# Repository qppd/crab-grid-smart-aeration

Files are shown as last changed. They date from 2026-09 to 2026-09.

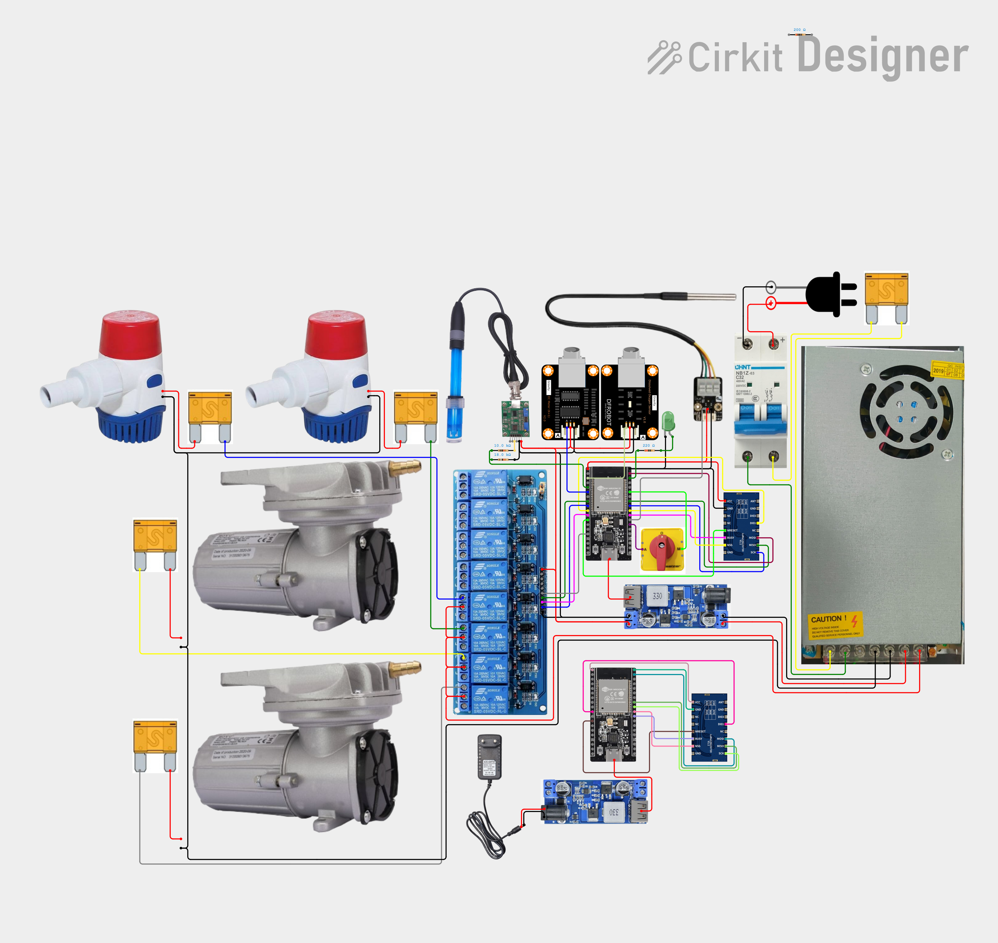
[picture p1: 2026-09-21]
wiring/circuit_image.png

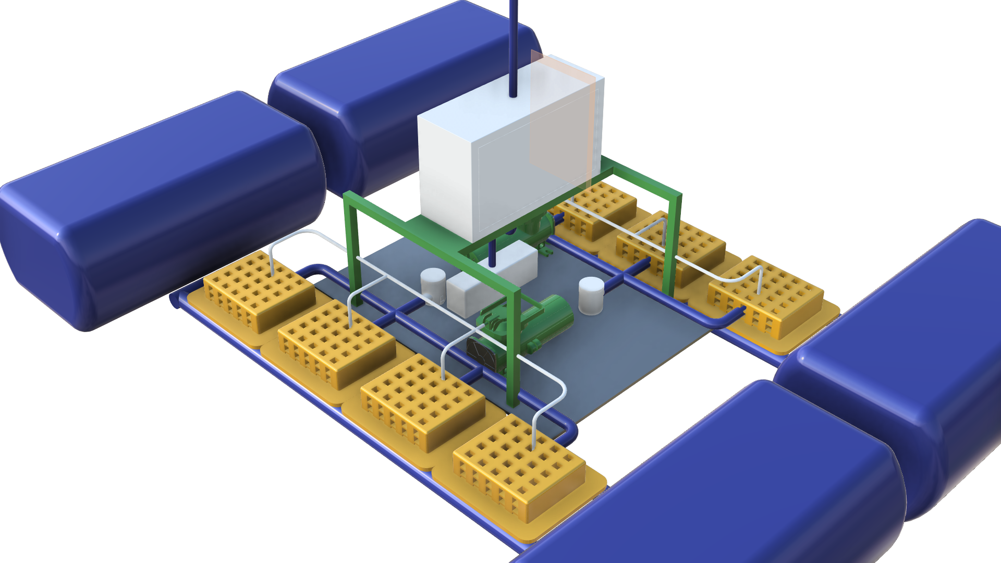
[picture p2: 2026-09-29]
model/SmartCrabAeration1.png

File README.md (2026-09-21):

<div align="center">

# Solar Automated LoRa-Integrated Mud Crab Aeration Network with Crab Grid Observation

A house-powered, remotely monitored smart aquaculture system for mud crab fattening in mangrove areas — combining physical crab separation, continuous water quality monitoring, automated aeration and alerts, LoRa remote control, and overhead visual security.





[]()

**Author:** [QPPD](https://www.github.com/qppd)

</div>

---

## Table of Contents

- [About the Project](#about-the-project)
- [Core Capabilities](#core-capabilities)
- [System Architecture](#system-architecture)
- [Structure & Layout](#structure--layout)
- [Electronics & Hardware](#electronics--hardware)
- [Power System](#power-system)
- [Software & Firmware](#software--firmware)
- [BOM & Budget](#bom--budget)
- [Getting Started](#getting-started)
  - [Prerequisites](#prerequisites)
  - [Hardware Setup](#hardware-setup)
  - [Firmware Installation](#firmware-installation)
  - [Dashboard Configuration](#dashboard-configuration)
- [Project Structure](#project-structure)
- [Compatibility Notes](#compatibility-notes)
- [Roadmap](#roadmap)
- [Contributing](#contributing)
- [License](#license)
- [Contact](#contact)

---

## About the Project

Mud crab (*Scylla serrata*) fattening is a vital livelihood in Southeast Asian mangrove communities, but crabs are notoriously cannibalistic — they eat each other when crowded or molting. Traditional farming relies on manual water monitoring, which is reactive rather than proactive. In these remote mangrove areas there is no utility grid and no Wi-Fi, and whatever power exists comes from small household solar systems — which makes conventional IoT solutions impractical.

This project solves these problems with a **low-power, remotely monitored aquaculture system** that:

1. Physically protects crabs using individual floating cages
2. Continuously senses water quality with multiple environmental sensors
3. Automatically triggers aeration and alerts; salinity correction is treated as a controlled test function, not a guaranteed open-water correction
4. Transmits data over **LoRa** to a bridge node at the house (where WiFi exists) for real-time remote monitoring
5. Provides visual security through an overhead camera system

The prototype is powered from the **household's existing solar installation** (220V AC, available 24/7 from the array, the inverter and a battery bank of over 600 Ah), so it needs no panels or batteries of its own — only a protected AC drop from the house to the float plus a 12V DC supply on site.

---

## Core Capabilities

| Feature | Description |
|---|---|
| **Physical Protection** | Individual floating cages (horizontal crab fattening boxes) physically separate crabs to prevent cannibalism. |
| **Water Quality Sensing** | Continuous monitoring of dissolved oxygen, pH, temperature and salinity — plus a pH/temperature-derived ammonia toxicity-risk indicator. Absolute NH₃ concentration requires a TAN measurement or laboratory test. |
| **Automated First Aid** | When conditions become dangerous, the system forces aeration, raises an alarm, and logs the event. Open-water salinity correction is not assumed; brine dosing is only valid in an isolated or closed-loop test enclosure. |
| **Manual & Automatic Control** | Runs itself in **AUTO** (firmware thresholds drive the pumps) and accepts **MANUAL** or **OFF** from the dashboard webapp, with a physical selector on the box as the fail-safe. |
| **Remote Monitoring & Control** | LoRa carries sensor data and pump commands to the house bridge node, which feeds the remote dashboard — even where there is no internet or Wi-Fi at the pond. |
| **Visual Security** | Overhead camera to monitor crab molting, deter animal predators, and spot human poachers. |

---

## System Architecture

```
                            ┌─────────────────────────────────────┐
                            │      REMOTE DASHBOARD (Next.js      │
                            │         + Firebase webapp)          │
                            └──────────────┬──────────────────────┘
                                           │ Internet / WiFi
                                           │
                            ┌──────────────┴──────────────────────┐
                            │  House Bridge Node (ESP32 + E22)    │
                            │  at the house, where WiFi exists    │
                            └──────────────┬──────────────────────┘
                                           │ LoRa (915 MHz, P2P)
                            ┌──────────────┴──────────────────────┐
                            │   ESP32 DevKit + E22 (SX1262)       │
                            │       — Main Controller Node        │
                            └──┬─────┬──────┬──────┬──────┬───────┘
                               │     │      │      │      │
                  ┌────────────┘     │      │      │      └────────────┐
                  │                  │      │      │                   │
          ┌───────┴────────┐  ┌─────┴────┐ │ ┌────┴───────┐  ┌───────┴──────┐
          │  Water Sensors │  │  Relay   │ │ │  Camera    │  │  House Solar │
          │  · EC/Salinity │  │  Module  │ │ │  ESP32-CAM-MB │  │  AC Feed     │
          │  · pH Probe    │  │  (8-Ch)  │ │ │  OV2640    │  │  · 220V 24/7 │
          │  · DS18B20 ×2  │  └────┬─────┘ │ └────────────┘  │  · RCD 30mA  │
          │  · DO Sensor   │       │       │                  │  · 12V 30A   │
          └────────────────┘  ┌────┴─────┐ │                  │    PSU       │
                              │ Actuators│ │                  └──────────────┘
                              │ · Air    │ │
                              │   Pumps  │ │
                              │ · Bilge  │ │
                              │   Pumps  │ │
                              └──────────┘ │
                                           │
                              ┌─────────────┴───────────┐
                              │   8 × Individual Crab   │
                              │   Fattening Boxes on     │
                              │   Foam Pontoon Grid      │
                              └─────────────────────────┘
```

---

## Structure & Layout

| Specification | Detail |
|---|---|
| **Pond Area** | 500 sqm (modular conceptual prototype) |
| **Capacity** | 8 individual fattening boxes on the pontoon grid, one crab per box (the anti-cannibalism constraint) |
| **Boxes & frames** | Slotted plastic boxes, shaded under the frame; frame/gantry preferably UV-stabilized PVC/FRP, or marine-grade timber sealed with marine epoxy/PU and Grade 316/nylon fasteners |
| **Floaters** | Ready-made foam-filled pontoon floats (×8–12), each with a manufacturer-rated buoyancy of at least 50 kg. Final sizing uses the measured dry above-water load and load distribution; water inside slotted cages is not counted as dead load while submerged. The PVC pipes are **conduit, never flotation**: water-filled pipe weighs ~1 kg per litre (see [Components.md](docs/Components.md)). |
| **Aeration** | 2 × RESUN MPQ-03 (MPQ-903) 12V air pumps (35W, 68 L/min open-flow, 6 outlets) + air stone per cage — regulate and measure the delivered flow. The biological target is approximately 4.8–6.4 L/min total for 320 L (1.5–2 L/min per 100 L), with N+1 redundancy. |
| **Air & water routing** | Two separate circuits inside the PVC pipe grid: an air header with per-cage drop tubes and stones, and a water header fed by the bilge pumps with a valved outlet per cage. Flexible hose runs from pump to cage are an option/backup |
| **Sensor hub** | Centred on the grid for balance and symmetric cable runs; probes at mid-depth (~20–30 cm), clear of the aerator plume. The DO probe must have gentle water movement across its membrane; one probe is a single-point risk, so use a handheld meter or scheduled aeration as a fallback. |
| **Controller & Power** | Controller centred in the setup for optimal wiring. Powered by a 220V AC drop from the household solar system (24/7) → shore-end 30 mA RCD + 2-pole breaker → weatherproof feedthroughs → 12V 30A DC supply. The AC installation and conductor/fuse sizing require a licensed electrician and Philippine Electrical Code review. |

> See [`Components.md`](docs/Components.md) for the full component specifications and [`docs/BOM.md`](docs/BOM.md) for the detailed Bill of Materials with verified product links and pricing.

---

## Electronics & Hardware

| Component | Specification | Purpose |
|---|---|---|
| **ESP32 DevKit 38-pin + EBYTE E22-900M22S (SX1262)** | ESP32-WROOM-32 + 915 MHz LoRa (SX1262, up to +22 dBm) | Main controller node — reads all sensors, runs automation logic, communicates over point-to-point LoRa on the 915 MHz ISM band. Verify measured EIRP and NTC type-approval before deployment. |
| **House Bridge Node (ESP32 + E22-900M22S)** | Same radio stack, at the house | LoRa ⇄ WiFi bridge — pushes float telemetry to the Firebase dashboard and relays dashboard commands back down over LoRa |
| **ESP32-CAM-MB** | OV2640, WiFi/BT | Overhead camera node for visual monitoring |
| **8-Channel Relay Module** | 12V coil, optocoupler, low-level trigger | Drives aerators and salinity pumps with spare channels |
| **DFRobot EC/Salinity Sensor** | K=10, 0–100 mS/cm | Measures conductivity/salinity. Use the manufacturer/PSS-78 conversion rather than a fixed 0.66 ppt-per-mS/cm rule; 35 ppt seawater is approximately 53 mS/cm at 25 °C. |
| **pH Electrode E-201-C** | PH-4502C analog board | Monitors pH (target: 7.5–8.5 for brackish water) |
| **DS18B20 Temperature Probes** | Waterproof, stainless steel ×2 | Digital temperature sensing (1-Wire) |
| **DFRobot Dissolved Oxygen Kit** | SEN0237-A, galvanic probe — **one unit (single measurement point)** | Measures dissolved oxygen — the #1 crab killer; mounted on the centred hub with water movement across the membrane. Carry a handheld DO meter and spare membrane/electrolyte because one probe is a single-point failure. |
| **12V DC Air Pumps (RESUN MPQ-03)** | Electromagnetic, 35W, 68 L/min open-flow, 0.068 MPa, ~3.5A, 6 outlets each ×2 | Oxygenation for all 8 cages; regulate each branch to the measured biological target (about 0.6–0.8 L/min per cage for 4.8–6.4 L/min total) + N+1 redundancy (alternating duty). Huge open-flow headroom covers depth/tubing/stone losses — must not be dumped unregulated into the cages. |
| **12V Marine Bilge Pumps** | 1100 GPH, submersible ×2 | Water circulation/flushing and a controlled salinity experiment. Do not claim reliable salinity correction in open slotted cages: tidal flushing and dense brine sinking will defeat dosing unless the cage is temporarily isolated or the test is closed-loop. |

---

## Power System

| Component | Specification |
|---|---|
| **AC Source** | 220V AC drop from the household solar system (array + **>600 Ah** battery bank + inverter) — available 24/7 |
| **AC Protection** | 30 mA RCD/GFCI + 2-pole breaker at the house end; outdoor-rated earthed cable (2.5 mm²) run overhead or in conduit; IP67/IP68 weatherproof connectors, drip loops, no submerged joints, monthly RCD test, and licensed-electrician commissioning. |
| **On-Site DC Supply** | 12V 30A (360 W) switching PSU → pumps, relay module, controller; LM2596S 24V/12V → 5V USB step-down module for the camera node. Treat 30A and the branch fuses as provisional until pump nameplate current, inrush, conductor ampacity, and voltage drop are measured and signed off. |

**Night load:** the planning estimate is ~50–60 W (≈ 5 A at 12 V) for aeration, but verify the actual pump duty cycle and inverter losses before relying on the household bank. The full Power Budget is in [`docs/BOM.md`](docs/BOM.md).

> **Single point of failure:** no on-site battery, so a tripped breaker or a cut cable stops aeration. The house bridge must alarm on heartbeat loss; use a local UPS/supercapacitor only if a last-gasp packet or unattended-night runtime is required.

---

## Software & Firmware

- **Microcontroller Firmware:** ESP32 (Arduino/PlatformIO) — sensor reading, LoRa P2P communication, relay control
- **LoRa Link:** point-to-point 915 MHz (E22-900M22S / SX1262) between the float node and the house bridge node — no LoRaWAN server (TTN/ChirpStack) needed. 915 MHz is the Philippine NTC licence-free SRD band for this low-duty telemetry; confirm maximum EIRP and type-approval before deployment.
- **Dashboard:** a **Next.js + Firebase (Realtime Database + Auth)** webapp — the house bridge node writes sensor data into the Realtime Database, and dashboard commands are read back and relayed down over LoRa
- **Camera:** WiFi-based streaming from ESP32-CAM-MB (local AP during pond visits)

### Control Modes

| Mode | Drives the pumps | When to use |
|---|---|---|
| **AUTO** (default) | Firmware thresholds — low salinity → bilge pump, low DO → aerator | Normal operation, and the fallback whenever anything else fails |
| **MANUAL** | The operator, per pump, from the webapp or the local selector | Testing, calibration, maintenance, harvest |
| **OFF** | Nobody — all actuators off | Servicing the float only; never while crabs are stocked |

Rules the firmware enforces:

- Boot, reset or link loss → **AUTO**, with aeration defaulting **ON**
- MANUAL auto-reverts to AUTO after 5 min without a command, so a forgotten switch cannot disable life-support aeration
- A DO reading below 3 ppm overrides MANUAL, forces aeration on, sends an immediate emergency uplink and raises an alarm
- The float sends a heartbeat at least every 60 seconds; the house bridge alarms on missed heartbeats
- Mode and pump state are echoed in every uplink, so the dashboard shows what the device actually believes

**Downlink packet:** device ID + sequence number + mode/pump command + expiry/ack field + CRC-8. The receiver validates the ID and CRC, applies the command only if it is fresh, and returns an ACK/NAK. Normal polling may be 5–15 minutes, but emergency sensor events bypass the schedule.

---

## BOM & Budget

Every part, price, product link and rating lives in [`docs/BOM.md`](docs/BOM.md), together with the compatibility verification and the power budget. Headline totals: **Tier 1 sensors ≈ ₱39,787–48,879**; **full sensor set ≈ ₱53,182–63,473** (per-category ranges are in the BOM).

Purchase is phased to match the project timeline — the four phases add up to the build total above (≈ **₱53,182–63,473** at item prices):

### Phase 1 — Bench Testing (~₱2,906)
2 × ESP32 DevKit + 2 × E22-900M22S/915 MHz antenna + DS18B20 + relay module + one bilge pump + the AUTO/OFF/MANUAL selector → build & test the control loop and the LoRa link on the bench (12V from a lab supply, or buy the on-site PSU now).

### Phase 2 — Remote Dashboard (~₱7,127–7,727)
House bridge node (ESP32 + E22-900M22S) + EC/salinity sensor + refractometer + calibration standard → close the remote monitoring loop.

### Phase 3 — Power to the Float (~₱3,127–4,969)
Protected 220V AC drop from the house (30 mA RCD + breaker) + 12V 30A DC supply + LM2596S camera module + fuses/glands → run the float off the household solar system. A licensed electrician must install and commission the mains side.

### Phase 4 — Full Feature Set (~₱34,850–46,400)
DO sensor + pH sensor (+ buffers) + ESP32-CAM-MB camera + second circulation pump + fattening boxes + frame/netting + **4× round foam floats 50×90** + the PVC air/water grid + sensor hub + air pumps + misc hardware + a controlled salinity-test setup → complete system before deployment. Open-water brine correction is not a guaranteed feature.

---

## Getting Started

### Prerequisites

- [Arduino IDE](https://www.arduino.cc/en/software) or [PlatformIO](https://platformio.org/)
- ESP32 board package (esp32 by Espressif)
- `RadioLib` (LoRa/SX1262 driver for the E22-900M22S) · `OneWire` / `DallasTemperature` (DS18B20) · `DFRobot_EC` / `DFRobot_pH` (DFRobot sensors)
- 3 × ESP32 DevKit 38-pin + 3 × E22-900M22S + 915 MHz antennas (float node, house bridge, spare — see [`docs/BOM.md`](docs/BOM.md) §1)
- pH/EC calibration standards and a handheld refractometer (see [`docs/BOM.md`](docs/BOM.md) §6)

### Hardware Setup

1. **Scaffold the floating grid** on foam-filled pontoon floats, with the frame and gantry in UV-stabilized PVC/FRP or properly sealed marine-grade material; use Grade 316 stainless or nylon fasteners in brackish water.
2. **Mount the 8 fattening boxes** on the grid, one crab per box, shaded from direct sun.
3. **Position the controller node** (ESP32 + E22-900M22S) in the centre of the setup in an IP65 enclosure.
4. **Connect the sensors** to the ESP32 ADC/GPIO pins per the pin map in [`Components.md`](docs/Components.md). For the minimum pH divider use 10 kΩ series + 18 kΩ shunt (5 V → about 3.21 V); for professional-grade pH, use an ADS1115 I2C ADC and 3.3 V level shifting.
5. **Wire the relay module** to the air pumps and bilge pumps, following the WiFi/boot-safe pin map in [`Components.md`](docs/Components.md) (no analog on ADC2 pins while WiFi runs, nothing on boot-strap pins 0/12/15).
6. **Run the power drop** — 220V AC from the house (30 mA RCD + breaker at the house end, weatherproof IP67/IP68 terminations, drip loops, no submerged joints) → 12V 30A DC supply on the float → fused distribution. Have a licensed electrician verify conductor size, earthing, breaker coordination and Philippine Electrical Code compliance.
7. **Calibrate before trusting any reading** — 2-point pH (4.01 / 6.86), EC with 1.413 mS/cm and 12.88 mS/cm standards following the sensor procedure, and cross-check salinity with the refractometer. Treat 12.88 mS/cm as a conductivity standard, not as 35 ppt seawater.

### Firmware Installation

1. Create the `firmware/` directory (planned — see [Project Structure](#project-structure)) and open it in Arduino IDE or PlatformIO.
2. Install required libraries:
   - `RadioLib` (SX1262 — the E22-900M22S needs RadioLib's SX126x driver; SPI SCK 18/MISO 19/MOSI 23/NSS 5, RST 14, DIO1 26, BUSY 17)
   - `OneWire` / `DallasTemperature` (DS18B20)
   - `DFRobot_EC` / `DFRobot_pH` (DFRobot sensors)
3. Configure the radio settings identically on every node (915 MHz, SF9–12, matching bandwidth/coding rate/sync word). Record the configured output/EIRP and confirm NTC type-approval for the 915 MHz SRD band.
4. WiFi stays **off** on the float node; only the house bridge joins the network.
5. Upload the firmware to each ESP32. Implement the device-ID/sequence/CRC-8 packet, ACK/NAK, 60-second heartbeat, immediate DO emergency uplink, and 5-minute MANUAL auto-revert before any life-support test.

### Dashboard Configuration

1. **Create the back end** — a Firebase project with the **Realtime Database** (live telemetry) and Firebase Auth for the farmer accounts.
2. **Deploy the webapp** — a Next.js app on Vercel's free tier (or Firebase Hosting), with the service-account values set as env vars: `FIREBASE_DATABASE_URL`, `FIREBASE_PROJECT_ID`, `FIREBASE_CLIENT_EMAIL`, `FIREBASE_PRIVATE_KEY`.
3. **Connect the uplinks** — the house bridge node relays each float packet into the Realtime Database (`devices/<id>/state`), where the webapp's `onValue()` listeners stream it straight to the UI.
4. **Build the control panel** — live readings, pump state, the AUTO/MANUAL/OFF selector, per-pump overrides and alert thresholds; a route handler writes the command into the Realtime Database where the house bridge polls it and relays it down over LoRa.

---

## Project Structure

```
crab-grid-smart-aeration/
├── README.md              # This file — start here
├── LICENSE                # MIT License
├── .gitignore
├── docs/                   # Documentation and builder guides
│   ├── Components.md      # Engineering specs and validation rationale
│   ├── HARDWARE.md        # Hardware guide (specs, pin map, BOM mirror)
│   ├── BOM.md             # Bill of Materials — prices, product links, ratings
│   ├── SETUP.md           # Environment, accounts and first power-up
│   ├── WIRING.md          # Assembly, wiring and verified ESP32 pin map
│   ├── FIRMWARE.md        # Firmware architecture and packet protocol
│   ├── TESTING.md         # Test plan and acceptance criteria
│   ├── CALIBRATION.md     # Sensor calibration procedures
│   ├── TROUBLESHOOTING.md # Fault isolation guide
│   ├── APP.md             # Dashboard webapp specification
│   ├── SYSTEM-ARCHITECTURE.md # Thesis system architecture diagram (Mermaid)
│   ├── BLOCK-DIAGRAM.md   # Thesis hardware block diagram (Mermaid)
│   ├── FLOWCHART.md       # Thesis operational flowchart (Mermaid)
│   ├── STACKS.md          # Technology stack reference
│   └── images/            # planned
├── firmware/              # planned — ESP32 source code
│   ├── main_controller/  # planned — ESP32+E22-900M22S sensor + LoRa firmware
│   ├── house_bridge/     # planned — LoRa ⇄ WiFi relay node firmware
│   └── camera_node/      # planned — ESP32-CAM-MB streaming firmware
└── dashboard/            # planned — Next.js + Realtime Database webapp

Items marked "planned" are not yet in the repository — create each item as its roadmap phase completes.
```

---

## Compatibility Notes

All system-level checks, with their verdicts, are in [`docs/BOM.md`](docs/BOM.md). The following gates still need action before deployment:

| Open item | Action |
|---|---|
| Camera is WiFi-only (video cannot fit LoRa) | Use its own AP during pond visits, run it at the house with the bridge node, or fit an LTE camera |
| No affordable NH₃ sensor | pH + temperature can estimate the toxic fraction/risk only; absolute NH₃ requires measured TAN or a laboratory test |
| PH-4502C outputs up to 5V | Use 10 kΩ series + 18 kΩ shunt for the minimum divider, or an ADS1115 for better precision |
| No on-site battery | Alert on heartbeat loss at the house bridge; confirm the house inverter stays on 24/7; add a small 12V UPS or supercapacitor if a last-gasp packet or unattended-night runtime is required |
| Control needs internet, hosting and the bridge node | Local selector as fail-safe; MANUAL auto-reverts to AUTO after 5 minutes; emergency sensor events bypass the polling interval; ACK/NAK confirms commands |

---

## Roadmap

- [x] Concept definition and documentation
- [x] Component selection and BOM verification
- [ ] Phase 1: Bench testing with ESP32 + E22-900M22S + basic sensors
- [ ] Phase 2: House bridge node integration and remote dashboard
- [ ] Phase 3: Power to the float (AC drop from household solar + 12V DC supply)
- [ ] Phase 4: Full feature set (DO, pH, camera, boxes)
- [ ] NTC/Philippine Electrical Code sign-off and licensed-electrician commissioning
- [ ] Field testing in mangrove environment
- [ ] System validation

---

## Contributing

Contributions are welcome! Please feel free to submit a Pull Request or open an Issue.

1. Fork the repository
2. Create your feature branch (`git checkout -b feature/amazing-feature`)
3. Commit your changes (`git commit -m 'Add some amazing feature'`)
4. Push to the branch (`git push origin feature/amazing-feature`)
5. Open a Pull Request

---

## License

Distributed under the MIT License. See [`LICENSE`](LICENSE) for more information.

---

## Contact

**QPPD** — [github.com/qppd](https://www.github.com/qppd)

Project Link: [https://github.com/qppd/crab-grid-smart-aeration](https://github.com/qppd/crab-grid-smart-aeration)

---

<div align="center">

**Built with love for sustainable aquaculture**

</div>

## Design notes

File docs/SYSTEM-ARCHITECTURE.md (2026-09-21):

# System Architecture

**Project:** Solar Automated LoRa-Integrated Mud Crab Aeration Network with Crab Grid Observation

This document describes the system architecture in the format required . The system is organized into five layers, from pond-side sensing to the cloud-hosted dashboard, connected by a 915 MHz LoRa point-to-point link where no WiFi exists.

## 1. Architecture Diagram

```mermaid
flowchart TB
    subgraph L1["Layer 1 - Sensing Layer (pond)"]
        S1["EC/salinity probe, K=10, 0-100 mS/cm"]
        S2["pH electrode E-201-C with PH-4502C board"]
        S3["DS18B20 temperature probes, 2 units"]
        S4["Dissolved oxygen probe, SEN0237-A"]
        S5["ESP32-CAM-MB OV2640 overhead camera"]
    end

    subgraph L2["Layer 2 - Edge Control Layer (float node)"]
        C1["ESP32 DevKit + EBYTE E22-900M22S, main controller"]
        C2["8-channel relay module, 12 V coil, low-level trigger"]
        C3["RESUN MPQ-03 air pumps, 2 units, N+1 alternating duty"]
        C4["12 V bilge pumps, 2 units, circulation and flushing"]
        C5["Local AUTO / OFF / MANUAL selector and status LEDs"]
    end

    subgraph L3["Layer 3 - Communication Layer"]
        R1["LoRa point-to-point link, 915 MHz, SX1262"]
    end

    subgraph L4["Layer 4 - Gateway Layer (house)"]
        G1["House bridge node, ESP32 + E22-900M22S"]
    end

    subgraph L5["Layer 5 - Application Layer"]
        F1["Firebase Realtime Database, live telemetry and command queue"]
        F2["Firebase Auth, farmer accounts"]
        D1["Next.js dashboard on Vercel free tier"]
    end

    S1 --> C1
    S2 --> C1
    S3 --> C1
    S4 --> C1
    S5 -. WiFi local AP during pond visits .-> D1
    C5 --> C1
    C1 --> C2
    C2 --> C3
    C2 --> C4
    C1 --> R1
    R1 --> G1
    G1 --> F1
    F1 --> D1
    D1 --> F1
    F1 --> G1
    G1 --> R1
    R1 --> C1
```

**Figure 1.** Five-layer system architecture of the automated aeration network.

## 2. Layer Descriptions

| Layer | Contents | Responsibility |
|---|---|---|
| 1 — Sensing | EC/salinity, pH, DO, 2 × DS18B20, overhead camera | Continuous water-quality measurement at mid-depth on a centred, removable hub |
| 2 — Edge control | ESP32 + E22, 8-channel relay, air pumps (N+1), bilge pumps, local selector | Runs the automation logic and first-aid rules autonomously; WiFi stays off |
| 3 — Communication | 915 MHz LoRa point-to-point (SX1262) | Uplinks telemetry and heartbeats; downlinks commands; no LoRaWAN server |
| 4 — Gateway | House bridge node (ESP32 + E22) where WiFi exists | Relays LoRa ↔ Firebase both directions; alarms on heartbeat loss |
| 5 — Application | Firebase Realtime Database + Auth; Next.js dashboard on Vercel | Live monitoring, control, parameter management, alerts, history ([`APP.md`](APP.md)) |

## 3. Data Flow

| Direction | Path | Contents |
|---|---|---|
| Uplink (≤ 60 s heartbeat) | Sensors → float node → LoRa → bridge → RTDB → dashboard | Scaled DO, pH, EC, temperatures, mode, pump bitmap, flags |
| Emergency uplink (immediate) | Same path | DO below 3 ppm bypasses the schedule with the emergency flag |
| Downlink (next uplink cycle) | Dashboard → RTDB → bridge → LoRa → float node | Mode command, pump overrides, threshold/config updates; ID + seq + expiry + CRC-8 validated |
| Local (no cloud) | Selector → float node | AUTO/MANUAL/OFF fail-safe control independent of any network |

## 4. Design Rationale

1. **Autonomy first.** The pond has no grid, no WiFi, and no operator on site; the float node must keep crabs alive alone — hence fail-safe AUTO, 5-minute MANUAL revert, and aeration ON at boot.
2. **Point-to-point over LoRaWAN.** A single pond-to-house link needs no gateway subscription; the house bridge is the only WiFi-capable radio node.
3. **Separation of concerns.** Sensing, control, communication, gateway, and application layers can each be tested and replaced independently (see [`TESTING.md`](TESTING.md) gates).
4. **Single points of failure are watched.** The DO probe (one unit) has a documented handheld-meter fallback; the AC drop (no on-site battery) is watched by the bridge's heartbeat-loss alarm.
5. **Compliance gates.** 915 MHz operation respects the Philippine NTC licence-free SRD band; the 220 V AC drop is a licensed-electrician installation under the Philippine Electrical Code.

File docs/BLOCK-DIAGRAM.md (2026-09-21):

# Hardware Block Diagram

**Project:** Solar Automated LoRa-Integrated Mud Crab Aeration Network with Crab Grid Observation

This document presents the hardware block diagram in the format required . It shows the float node's power chain, controller, sensor cluster, LoRa radio, relay-driven actuators, and local interface, plus the radio link to the house bridge. Pin numbers follow the verified map in [`WIRING.md`](WIRING.md) §3.

## 1. Block Diagram

```mermaid
flowchart LR
    subgraph PWR["Power System"]
        AC["220 V AC from household solar, 24/7"] --> RCD["30 mA RCD + 2-pole breaker, shore end"]
        RCD --> PSU["12 V 30 A switching PSU, 360 W"]
        PSU --> BUCK["LM2596S 24 V/12 V to 5 V USB step-down"]
    end

    subgraph CTRL["Main Controller"]
        CORE["ESP32 DevKit 38-pin, ESP32-WROOM-32"]
    end

    subgraph SEN["Sensor Cluster"]
        S1["pH analog output to GPIO 34, ADC1"]
        S2["EC/salinity analog output to GPIO 35, ADC1"]
        S3["DO analog output to GPIO 36, ADC1"]
        S4["2x DS18B20 shared 1-Wire bus on GPIO 16"]
    end

    subgraph RAD["LoRa Radio"]
        R1["EBYTE E22-900M22S, SX1262: SPI 18/19/23/5, RST 14, DIO1 26, BUSY 17"]
    end

    subgraph RLY["Relay Module, 8-channel, GPIO 25 / 27 / 33 / 13"]
        K1["Channel 1"]
        K2["Channel 2"]
        K3["Channel 3"]
        K4["Channel 4"]
    end

    subgraph ACT["Actuators"]
        P1["RESUN MPQ-03 air pump 1, 35 W"]
        P2["RESUN MPQ-03 air pump 2, 35 W"]
        P3["12 V bilge pump 1, 1100 GPH"]
        P4["12 V bilge pump 2, 1100 GPH"]
    end

    subgraph LOC["Local Interface"]
        H1["3-position rotary selector on GPIO 4 and 21"]
        H2["Mode and status LEDs on GPIO 22 and 2"]
    end

    BR["House bridge node, ESP32 + E22-900M22S"]
    V1["ESP32-CAM-MB OV2640, 5 V from LM2596S module, WiFi AP only"]

    PSU --> CORE
    PSU --> K1
    BUCK --> V1
    S1 --> CORE
    S2 --> CORE
    S3 --> CORE
    S4 --> CORE
    CORE --> R1
    R1 --> CORE
    R1 -. 915 MHz LoRa point-to-point, uplink and downlink .-> BR
    CORE --> K1
    CORE --> K2
    CORE --> K3
    CORE --> K4
    K1 --> P1
    K2 --> P2
    K3 --> P3
    K4 --> P4
    H1 --> CORE
    CORE --> H2
```

**Figure 1.** Hardware block diagram of the float node and its link to the house bridge.

## 2. Block Descriptions

| Block | Function | Key interfaces |
|---|---|---|
| Power system | 220 V AC from the household solar installation, protected by a shore-end 30 mA RCD, converted to 12 V DC and 5 V DC | Licensed-electrician AC side; 12 V feeds pumps, relays and controller; 5 V feeds the camera |
| Main controller | ESP32-WROOM-32 runs the automation logic, LoRa protocol, and fail-safe rules | Three ADC1 analog inputs, 1-Wire, VSPI to the radio, four relay outputs |
| Sensor cluster | DO, pH, EC/salinity, and two temperature probes | Analog on GPIO 34/35/36 (ADC1); DS18B20 pair on GPIO 16 with a 4.7 kΩ pull-up |
| LoRa radio | EBYTE E22-900M22S (SX1262) at 915 MHz | SPI 18/19/23, NSS 5, RST 14, DIO1 26, BUSY 17; 3.3 V logic only |
| Relay module | 8-channel, 12 V coil, optocoupler, low-level trigger; four channels used, four spare | External 10 kΩ pull-ups hold relays OFF through boot and reset |
| Actuators | Two RESUN MPQ-03 air pumps (N+1 alternating duty) and two bilge pumps | Branch-fused 12 V feeds; per-cage valves on the water header |
| Local interface | 3-position AUTO/OFF/MANUAL selector and status LEDs | Active-LOW decode on GPIO 4/21; LEDs on GPIO 22/2 |
| Camera node | ESP32-CAM-MB OV2640 for overhead visual monitoring | WiFi AP during pond visits; never streams over LoRa |
| House bridge | Second ESP32 + E22 at the house | Relays LoRa ↔ Firebase in both directions |

## 3. Design Notes

1. All analog sensors sit on **ADC1** so the pin map stays valid even if WiFi is later enabled on a node ([`WIRING.md`](WIRING.md) §4).
2. No actuator is connected to a boot-strapping pin; GPIO 0, 12, 15 and UART0 pins 1/3 remain unconnected.
3. The relay module's low-level trigger is boot-safe: firmware drives the GPIOs HIGH before initialization and external pull-ups keep the inputs released during reset.
4. The pipe grid carries the air and water headers as separate circuits; it is conduit, never flotation ([`Components.md`](Components.md) — Floaters).

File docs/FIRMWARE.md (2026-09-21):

# Firmware Guide

**Project:** Solar Automated LoRa-Integrated Mud Crab Aeration Network with Crab Grid Observation

Design reference for the three ESP32 firmware targets. The controlling principles: **fail-safe to AUTO with aeration ON**, **WiFi stays off on the float**, and the system must keep crabs alive with zero internet, zero cloud, and zero operator.

## 1. Targets and Layout

```
firmware/
├── main_controller/    # Float node: sensors, control loop, LoRa
├── house_bridge/       # Bridge node: LoRa <-> Firebase relay + alarms
├── camera_node/        # ESP32-CAM-MB: WiFi AP stream only
└── shared/
    ├── pins.h          # Pin map (verified in WIRING.md §3)
    ├── packets.h       # Frame layouts and CRC-8
    └── config.h        # Device ID, radio, thresholds, timing
```

Libraries: `RadioLib` (SX1262), `OneWire` + `DallasTemperature`, `DFRobot_EC`, `DFRobot_pH`; the bridge adds the Mobizt `Firebase Arduino Client` library for Realtime Database writes.

## 2. Control Rules (enforced in firmware)

| Rule | Behavior |
|---|---|
| Boot, reset, or link loss | Mode = **AUTO**, aeration **ON** |
| MANUAL timeout | Auto-reverts to AUTO after **5 minutes** without a fresh command (`MANUAL_REVERT_MS`, configurable 1–30 min) |
| DO emergency | DO below 3 ppm overrides any mode, forces aeration ON, raises the local alarm, and sends an **immediate emergency uplink** |
| Heartbeat | One uplink at least every **60 s**; mode and pump state echoed in every frame |
| Command validation | Device ID + sequence + expiry + CRC-8 all checked; stale or corrupt frames are NAKed |
| OFF | All actuators off; exists for servicing only |
| Boot-safe outputs | Relay GPIOs driven HIGH (relays off) **before** pin init; external pull-ups hold relays off through reset ([`WIRING.md`](WIRING.md) §4) |

## 3. Pin Map (summary)

The full conflict verification is in [`WIRING.md`](WIRING.md) §3–4. Quick map: LoRa SPI 18/19/23, NSS 5, RST 14, DIO1 26, BUSY 17; 1-Wire 16; pH 34, EC 35, DO 36 (all ADC1); relays 25/27/33/13; selector 4 (A) and 21 (B); mode LED 22, link LED 2; spare 32 and 39; leave 0/12/15 and 1/3 unconnected.

## 4. Radio Configuration (identical on every node)

| Setting | Value |
|---|---|
| Frequency | 915.0 MHz (PH NTC licence-free SRD band — confirm measured EIRP and type-approval) |
| Spreading factor | SF9 (SF7–12 supported) |
| Bandwidth / coding rate | 125 kHz / 4-5 |
| Preamble | 8 |
| Sync word | 0x3444 (private; never LoRaWAN public) |
| CRC | On |
| TX power | Within the NTC EIRP limit |

## 5. Packet Protocol

All frames end in **CRC-8 (poly 0x07)** computed over the preceding bytes. Multi-byte values are little-endian, scaled ×100.

### 5.1 Uplink — float to bridge (17 bytes)

| Byte | Field | Notes |
|---|---|---|
| 0 | Device ID | 1 = float |
| 1–2 | Sequence number | uint16, increments per frame |
| 3 | Flags | Bits 0–1 mode (0 AUTO, 1 MANUAL, 2 OFF); bit 2 emergency (DO event); bit 3 sensor fault |
| 4 | Pump bitmap | Bit 0 air1, bit 1 air2, bit 2 bilge1, bit 3 bilge2 |
| 5–6 | DO (ppm ×100) | uint16 |
| 7–8 | pH (×100) | uint16 |
| 9–10 | EC (mS/cm ×100) | uint16 |
| 11–12 | Temperature 1 (°C ×100) | int16 |
| 13–14 | Temperature 2 (°C ×100) | int16 |
| 15 | Status/reserved | Uplink interval, uptime bucket |
| 16 | CRC-8 | Over bytes 0–15 |

### 5.2 Downlink — bridge to float (8 bytes)

| Byte | Field | Notes |
|---|---|---|
| 0 | Device ID | Must match |
| 1–2 | Command sequence | Echoed in the ACK |
| 3 | Mode command | 0 AUTO, 1 MANUAL, 2 OFF, 255 = no change |
| 4 | Pump override bitmap | 0xFF = no change; bits as uplink |
| 5–6 | Expiry (s) | Command invalid after this window |
| 7 | CRC-8 | Over bytes 0–6 |

### 5.3 ACK/NAK — float to bridge (4 bytes)

Byte 0 device ID; byte 1 `0x06` ACK or `0x15` NAK; byte 2 echoed command sequence (low byte); byte 3 CRC-8.

## 6. Timing

| Timer | Value | Purpose |
|---|---|---|
| Heartbeat/uplink | 60 s (`HEARTBEAT_MS`) | Telemetry + command check each cycle; a future low-power build may stretch this to 5–15 min |
| Emergency uplink | Immediate | DO below 3 ppm bypasses the schedule |
| MANUAL revert | 5 min | No fresh command → AUTO |
| Command expiry | Set per command | Reject stale downlinks |
| Sensor sampling | 1 s sample / 15 s average | Smooth ADC noise before uplink |
| Heartbeat-loss alarm (bridge) | No uplink for 90 s | Local alarm + RTDB alert |

## 7. Sensor Pipeline

1. Read DS18B20 pair over 1-Wire; pH/EC/DO through the DFRobot libraries with the calibration constants from [`CALIBRATION.md`](CALIBRATION.md).
2. Apply the pH divider correction (or use ADS1115 values directly) and temperature compensation per library docs.
3. Flag a **sensor fault** when a reading is physically impossible (e.g., pH outside 0–14, DS18B20 returns −127) — the fault bit rides the next uplink.
4. Persist calibration constants in NVS/EEPROM so a reboot never loses calibration.

## 8. House Bridge Node

- Receives uplinks, verifies ID + CRC-8, writes to `devices/<id>/state` and trims `logs/<id>/<timestamp>` (schema in [`APP.md`](APP.md) §2).
- Polls `commands/<id>/queue` every uplink cycle, relays fresh commands downlink, and marks each command `acked` / `naked` / `expired`.
- Raises the **heartbeat-loss alarm** after 90 s of silence (local LED/buzzer plus an RTDB alert) — this is the single-point-of-failure watchdog for the life-support load.
- WiFi joins the home network; the float node's WiFi is never enabled.

## 9. config.h Defaults

| Key | Default | Allowed range |
|-----|---|---|
| `DEVICE_ID` | 1 (float), 2 (bridge) | 1–254 |
| `RF_FREQ_MHZ` | 915.0 | fixed by NTC band |
| `RF_SF` / `RF_BW_KHZ` / `RF_CR` | 9 / 125 / 5 | identical on all nodes |
| `HEARTBEAT_MS` | 60000 | 30000–300000 |
| `MANUAL_REVERT_MS` | 300000 | 60000–1800000 |
| `DO_EMERGENCY_PPM` | 3.0 | 2.0–4.0 |
| `DO_TARGET_PPM` | 5.0 | 4.0–7.0 |
| `SAL_MIN_PPT` / `SAL_MAX_PPT` | 28 / 32 | 10–34 (min < max) |
| `PH_MIN` / `PH_MAX` | 7.5 / 8.5 | 6.5–9.0 (min < max) |
| `TEMP_MIN_C` / `TEMP_MAX_C` | 27 / 30 | 20–35 (min < max) |

Dashboard-side edits to thresholds arrive as config downlinks and are clamped to these ranges ([`APP.md`](APP.md) §6).

## 10. Camera Node (ESP32-CAM-MB)

- Uses the stock AI-Thinker OV2640 pinout; **no LoRa** — video cannot fit the LoRa link.
- Runs a WiFi **access point** (`crabcam-<id>`) joined by the farmer's phone during pond visits.
- Power: 5 V at ≥ 2 A from the LM2596S module; brownouts are the usual camera fault (see [`TROUBLESHOOTING.md`](TROUBLESHOOTING.md) §6).

## 11. Building and Flashing

1. Board: **ESP32 Dev Module**; flash 4 MB; upload 115200–921600; CPU 240 MHz.
2. Select the right COM port; hold **BOOT** if "Connecting..." never completes.
3. Flash the float node **before** wiring pumps, and confirm serial logs show sensor init and the first uplink.
4. Flash the bridge, then the camera last.
5. Version-tag every field deployment in git so a known-good firmware can be re-flashed at the pond.

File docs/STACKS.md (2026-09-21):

# Technology Stack

**Project:** Solar Automated LoRa-Integrated Mud Crab Aeration Network with Crab Grid Observation

A layer-by-layer reference of every technology the system uses, from the pond hardware to the hosted dashboard. Selection rationale and validation notes live in [`Components.md`](Components.md); the architecture view is in [`SYSTEM-ARCHITECTURE.md`](SYSTEM-ARCHITECTURE.md).

## 1. Stack at a Glance

```mermaid
flowchart TB
    N1["Next.js dashboard on Vercel"] --> F1["Firebase Realtime Database + Auth"]
    F1 --> B1["House bridge node, ESP32 + E22, WiFi"]
    B1 -. "915 MHz LoRa point-to-point" .-> N2["Float node, ESP32 + E22"]
    N2 --> H1["Sensors, relay module, air and bilge pumps on 12 V"]
```

**Figure 1.** Technology stack, from the hosted dashboard down to the pond hardware.

## 2. Hardware Stack

| Layer | Component | Qty | Role |
|---|---|-----|---|
| Edge controller | ESP32 DevKit 38-pin (ESP32-WROOM-32) | 3 (float, bridge, spare/dev) | Runs control logic and the LoRa link |
| Radio | EBYTE E22-900M22S (SX1262, 915 MHz) | 3 | Long-range point-to-point telemetry |
| Observation | ESP32-CAM-MB (OV2640) | 1 | Overhead visual monitoring over a WiFi AP |
| Sensing | DFRobot EC K=10, pH E-201-C + PH-4502C, DS18B20 ×2, DO SEN0237-A | 1 ea (temp ×2) | Water-quality measurement |
| Actuation | 8-channel relay, 2 × RESUN MPQ-03 air pumps, 2 × bilge pumps 1100 GPH | 1 set | Aeration and circulation |
| Power | 220 V AC drop + 30 mA RCD, 12 V 30 A PSU, LM2596S 5 V module | 1 set | Household-solar-fed power chain |
| Structure | 8 slotted fattening boxes, foam pontoons, PVC air/water grid, sensor hub | 1 set | Floating cage grid on the pond |

## 3. Firmware Stack

| Technology | Used by | Purpose |
|---|---|---|
| Arduino framework on ESP32 (Arduino IDE or PlatformIO) | all nodes | Build system and runtime |
| `RadioLib` | float, bridge | SX1262 driver for the E22-900M22S |
| `OneWire` + `DallasTemperature` | float | DS18B20 probes |
| `DFRobot_EC` / `DFRobot_pH` | float | EC and pH conversion with calibration |
| `Firebase Arduino Client Library` (Mobizt) | bridge | Realtime Database writes |
| NVS/EEPROM storage | float | Calibration constants and config persistence |

Protocol details (frames, CRC-8, ACK/NAK, heartbeat) are specified in [`FIRMWARE.md`](FIRMWARE.md) §5.

## 4. Communication Stack

| Link | Technology | Notes |
|---|---|---|
| Pond ↔ house | LoRa point-to-point, 915 MHz (E22/SX1262), SF9, BW 125 kHz, CR 4-5, private sync word | Philippine NTC licence-free SRD band; confirm measured EIRP and type-approval |
| House ↔ cloud | Home WiFi via the bridge node | The only internet-dependent hop |
| Phone ↔ camera | WiFi AP (`crabcam-<id>`) | Pond-visit monitoring; video never traverses LoRa |
| Packet integrity | Device ID, sequence, expiry, CRC-8, ACK/NAK, 60 s heartbeat | Defined in [`FIRMWARE.md`](FIRMWARE.md) §5 |

## 5. Backend Stack

| Technology | Role |
|---|---|
| Firebase Realtime Database | Live telemetry (`devices/<id>/state`), command queue, trimmed logs |
| Firebase Auth (Email/Password) | Farmer and admin accounts; Auth-only database rules |
| Service account (Vercel env vars) | Server-side database access; key never shipped to the client |

Schema: [`APP.md`](APP.md) §2.

## 6. Frontend Stack

| Technology | Role |
|---|---|
| Next.js (React) | Dashboard UI: monitoring, control, parameters, alerts, history |
| Vercel Hobby tier | Free hosting with the four Firebase env vars |
| RTDB `onValue()` listeners | Live streaming state into the UI |

Feature specification and safety interlocks: [`APP.md`](APP.md) §1 and §5.

## 7. Development and Documentation Tools

| Tool | Use |
|---|-----|
| Arduino IDE / PlatformIO | Firmware builds and flashing |
| Git + GitHub | Version control; tagged field deployments |
| Node.js LTS | Dashboard development and build |
| Mermaid | Thesis diagrams ([`FLOWCHART.md`](FLOWCHART.md), [`SYSTEM-ARCHITECTURE.md`](SYSTEM-ARCHITECTURE.md), [`BLOCK-DIAGRAM.md`](BLOCK-DIAGRAM.md), Figure 1 above) |
| Markdown documentation set | Builder guides: [`SETUP.md`](SETUP.md), [`WIRING.md`](WIRING.md), [`TESTING.md`](TESTING.md), [`CALIBRATION.md`](CALIBRATION.md), [`TROUBLESHOOTING.md`](TROUBLESHOOTING.md) |

## 8. Explicit Non-Dependencies

1. **No LoRaWAN server** (TTN/ChirpStack) — the link is plain point-to-point to the house bridge.
2. **No on-site solar panels, MPPT, or battery** — power comes from the household's existing 24/7 solar-backed installation.
3. **No paid hosting** — Firebase Spark and Vercel Hobby free tiers cover the project scale.

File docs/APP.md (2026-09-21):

# Dashboard Application (APP) Specification

**Project:** Solar Automated LoRa-Integrated Mud Crab Aeration Network with Crab Grid Observation

The webapp is a **Next.js + Firebase Realtime Database + Auth** application on Vercel's free tier. It gives the farmer live monitoring, safe remote control (AUTO/MANUAL/OFF and per-pump overrides), and remote parameter editing — while the local selector remains the fail-safe ([`Components.md`](Components.md) — Control Interface).

## 1. Feature Set

| Area | Features |
|---|---|
| Monitoring | Live DO, pH, salinity/EC, temperature ×2, mode, pump states, link quality (RSSI/SNR), last-seen time, stale-data banner |
| Control | AUTO / MANUAL / OFF mode selector, per-pump overrides in MANUAL, ACK/NAK feedback, MANUAL revert countdown |
| Parameters | Threshold editor with range validation, written to the device config and relayed to the float on the next downlink |
| Alerts | DO emergency, threshold breach, heartbeat loss, sensor fault, command NAK/expired |
| History | Trimmed log in RTDB, 24 h / 7 d charts, CSV export for data |
| Admin | Device registry, farmer/admin roles via Firebase Auth, calibration due-date reminders |

## 2. Realtime Database Schema

```
devices/
  <deviceId>/
    state/            # written by the house bridge from each uplink
      mode: "AUTO" | "MANUAL" | "OFF"
      pumps: { air1, air2, bilge1, bilge2 }
      do, ph, ec, temp1, temp2        # scaled values
      rssi, snr, seq, emergency, sensorFault
      lastSeen: <serverTimestamp>
    config/
      device/    { name, location, radio: { freq, sf, bw, cr } }
      thresholds/ { doEmergency, doTarget, salMin, salMax, phMin, phMax,
                    tempMin, tempMax, manualRevertMin, aerationOn, aerationOff }
      calibration/ { phDue, ecDue, doDue }     # ISO dates, drives reminders
commands/
  <deviceId>/
    queue/<pushKey>/
      cmdId, mode, pumpBitmap, expiryMs, issuedBy, issuedAt
      status: "pending" | "sent" | "acked" | "naked" | "expired"
logs/
  <deviceId>/<timestamp>/   # trimmed history; the UI offers CSV export
users/
  <uid>/ { name, role: "farmer" | "admin" }
```

## 3. Pages

1. **Dashboard** — live cards for every value in `state/`; a STALE banner when `lastSeen` is older than 90 s (heartbeat-loss rule, [`FIRMWARE.md`](FIRMWARE.md) §6).
2. **Control** — mode selector with confirmations; per-pump switches enabled only in MANUAL; each command shows its ACK/NAK result and expiry; MANUAL shows a live revert countdown.
3. **Parameters** — threshold editor (§6 validation table); writes land in `config/thresholds` with `issuedBy` + timestamp, and the bridge relays them as a config downlink; firmware clamps values again (defense in depth).
4. **Alerts** — alert list and history; in-app banners now, email/SMS hooks later.
5. **History** — charts (24 h / 7 d) from `logs/`, CSV export for data charts.
6. **Devices** — registry and roles; admins manage devices and users.
7. **Camera** — instructions to join the camera's WiFi AP (`crabcam-<id>`) during pond visits; the camera is WiFi-only by design and never streams over LoRa.

## 4. Command Flow

```mermaid
sequenceDiagram
    participant U as Operator (webapp)
    participant RT as Firebase Realtime Database
    participant B as House bridge node
    participant F as Float node

    U->>RT: Write command (mode or pump override)
    B->>RT: Poll command queue on each uplink cycle
    RT-->>B: Pending command
    B->>F: LoRa downlink: ID, seq, mode, pumps, expiry, CRC-8
    F-->>B: ACK (applied) or NAK (rejected)
    B->>RT: Mark command acked or nacked
    F->>B: Next uplink echoes mode and pump state
    B->>RT: Update devices/id/state
    RT-->>U: Live UI update via onValue()
```

Command latency is one uplink cycle (≤ 60 s); DO emergencies bypass the schedule entirely ([`FIRMWARE.md`](FIRMWARE.md) §5–6).

## 5. Safety Interlocks

| Interlock | Behavior |
|---|---|
| Aeration lock | Aeration cannot be fully disabled while DO is below `doEmergency` — rejected in the UI, re-checked in firmware |
| OFF confirmation | OFF requires a typed confirmation warning that crabs must not be stocked |
| MANUAL revert | MANUAL auto-reverts to AUTO after `manualRevertMin` without a fresh command (default 5 min); the UI shows the countdown |
| Command expiry | Every command carries an expiry; stale commands are NAKed |
| Fail-safe default | Boot, reset, or link loss → AUTO with aeration ON |
| Local authority | The physical selector overrides the dashboard at the device |

## 6. Threshold Validation Ranges

| Parameter | Default | Allowed range | Unit |
|---|---|---|---|
| `doEmergency` | 3.0 | 2.0–4.0 | ppm |
| `doTarget` | 5.0 | 4.0–7.0 | ppm |
| `salMin` | 28 | 10–34 | ppt |
| `salMax` | 32 | 10–34 (must exceed `salMin`) | ppt |
| `phMin` | 7.5 | 6.5–8.5 | pH |
| `phMax` | 8.5 | 7.0–9.0 (must exceed `phMin`) | pH |
| `tempMin` | 27 | 20–33 | °C |
| `tempMax` | 30 | 22–35 (must exceed `tempMin`) | °C |
| `manualRevertMin` | 5 | 1–30 | min |
| `aerationOn` / `aerationOff` | 18:00 / 06:00 | HH:MM | optional night schedule |

## 7. Alerts

| Alert | Trigger | Path |
|---|---|---|
| DO emergency | `state.do < doEmergency` | Immediate emergency uplink flag; red banner; logged |
| Threshold breach | Any value outside its band for two consecutive uplinks | Banner + alert history |
| Heartbeat loss | No uplink for 90 s | Bridge local alarm **and** dashboard banner — the bridge alarms even when the internet is down |
| Sensor fault | `state.sensorFault` bit or impossible values | Banner + history |
| Command NAK/expired | `commands/.../status` | Shown next to the command |

## 8. Non-Functional Requirements

1. **Free tier budget:** keep live state in one node, trim `logs/<id>` (e.g., last 7 days) so RTDB stays inside the Spark plan.
2. **Security:** Auth-only database rules ([`SETUP.md`](SETUP.md) §5); the service-account key exists only server-side as Vercel env vars — never in client code.
3. **Offline behavior:** if the house internet drops, the dashboard goes stale but the bridge keeps alarming locally and the float keeps running AUTO.
4. **Auditability:** every command and threshold edit records `issuedBy` and a timestamp for the audit log.

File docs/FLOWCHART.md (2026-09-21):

# System Flowchart

**Project:** Solar Automated LoRa-Integrated Mud Crab Aeration Network with Crab Grid Observation

This document presents the operational flowchart of the system in the format required . It traces one complete control cycle: sensor acquisition and automatic first-aid logic at the float node, LoRa transmission to the house bridge node, telemetry storage in Firebase, dashboard command relay, and the fail-safe mode rules enforced by the firmware ([`FIRMWARE.md`](FIRMWARE.md) §2).

## 1. Flowchart

```mermaid
flowchart TD
    subgraph FLOAT["Float Node - ESP32 + E22-900M22S (pond side)"]
        A([Start: power on or reset]) --> B[Initialize GPIO, sensor interfaces, relays and LoRa radio]
        B --> C[Initialize mode: AUTO with aeration ON]
        C --> D{Local selector mode}
        D -->|OFF| E[Keep all actuators off]
        D -->|MANUAL| F[Apply operator command from selector or webapp]
        F --> F1{No command received for 5 minutes?}
        F1 -->|Yes| D
        D -->|AUTO| G[Read DO, pH, EC/salinity and temperature probes]
        G --> H{DO below 3 ppm?}
        H -->|Yes| I[Force aeration ON and raise alarm]
        I --> I1[Queue immediate emergency uplink]
        H -->|No| J{Salinity below threshold?}
        J -->|Yes| K[Energize assigned bilge pump]
        J -->|No| L[Run scheduled aeration per thresholds]
        M[Compose uplink: sensor data, mode, pump state and heartbeat]
        E --> M
        F1 -->|No| M
        I1 --> M
        K --> M
        L --> M
        M --> N[Transmit LoRa packet to the house bridge]
        N --> O{Downlink command received?}
        O -->|Yes| P[Validate device ID, sequence, expiry and CRC-8]
        P -->|Valid and fresh| Q[Apply mode and pump command, return ACK]
        P -->|Invalid or stale| R[Return NAK and keep current mode]
        O -->|No| S[Wait for the next heartbeat cycle]
        Q --> D
        R --> D
        S --> D
    end

    subgraph BRIDGE["House Bridge Node - ESP32 + E22-900M22S (where WiFi exists)"]
        T[Receive uplink and verify device ID and CRC-8] --> U[Write telemetry to the Firebase Realtime Database]
        U --> V[Poll the Realtime Database for queued commands]
        V --> W{Fresh dashboard command queued?}
        W -->|Yes| X[Send the command downlink over LoRa]
        X --> Y{ACK received from the float node?}
        Y -->|Timeout or NAK| X
        Y -->|ACK| Z[Wait for the next uplink]
        W -->|No| Z
    end

    subgraph DASH["Remote Dashboard - Next.js + Firebase on Vercel"]
        AA["onValue() listeners stream live telemetry to the web UI"] --> AB[Operator selects mode or per-pump override]
        AB --> AC[Route handler writes the command into the Realtime Database]
    end

    N --> T
    AC --> V
```

**Figure 1.** Overall operational flowchart of the Solar Automated LoRa-Integrated Mud Crab Aeration Network.

## 2. Flow Description

1. **Initialization.** On power-up or reset the node forces mode AUTO with aeration ON — the fail-safe default ([`FIRMWARE.md`](FIRMWARE.md) §2).
2. **Mode selection.** The local selector decodes AUTO, MANUAL, or OFF ([`WIRING.md`](WIRING.md) §6). OFF exists for servicing only.
3. **Automatic first aid.** In AUTO the firmware reads dissolved oxygen, pH, EC/salinity, and temperature. DO below 3 ppm overrides every mode, forces aeration, and triggers an immediate emergency uplink.
4. **Salinity logic.** A sub-threshold salinity run engages the assigned bilge pump for flushing or controlled brine testing; open-water salinity correction is not claimed ([`Components.md`](Components.md) — Water circulation).
5. **Uplink.** Every cycle composes one frame — sensor data, mode, pump state, heartbeat — transmitted over 915 MHz LoRa point-to-point.
6. **Downlink handling.** Commands are accepted only when the device ID, sequence, expiry window, and CRC-8 all validate; otherwise the float returns a NAK and keeps its current mode.
7. **Bridge and cloud.** The house bridge verifies each uplink, writes telemetry to the Realtime Database, relays queued dashboard commands downlink, and tracks ACK/NAK results.
8. **Dashboard.** `onValue()` listeners stream the live state to the web UI; operator commands enter the Realtime Database queue ([`APP.md`](APP.md) §4).

## 3. Fail-Safe Notes

- MANUAL auto-reverts to AUTO after 5 minutes without a fresh command.
- Heartbeat loss beyond 90 s raises an alarm at the house bridge.
- The physical selector always overrides dashboard intent at the device.

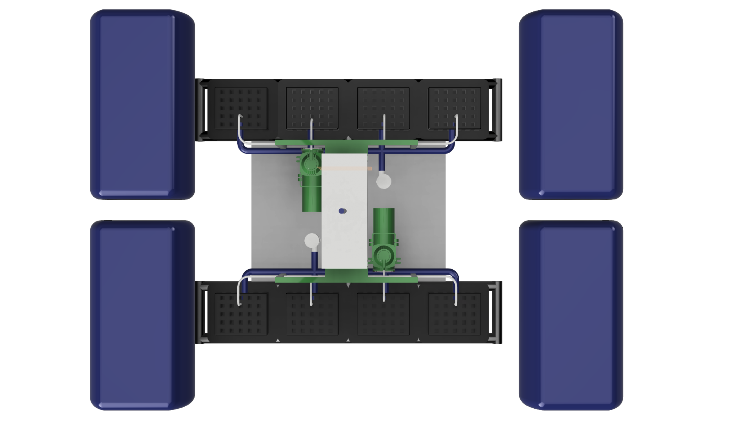
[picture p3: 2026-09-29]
model/SmartCrabAeration3.png

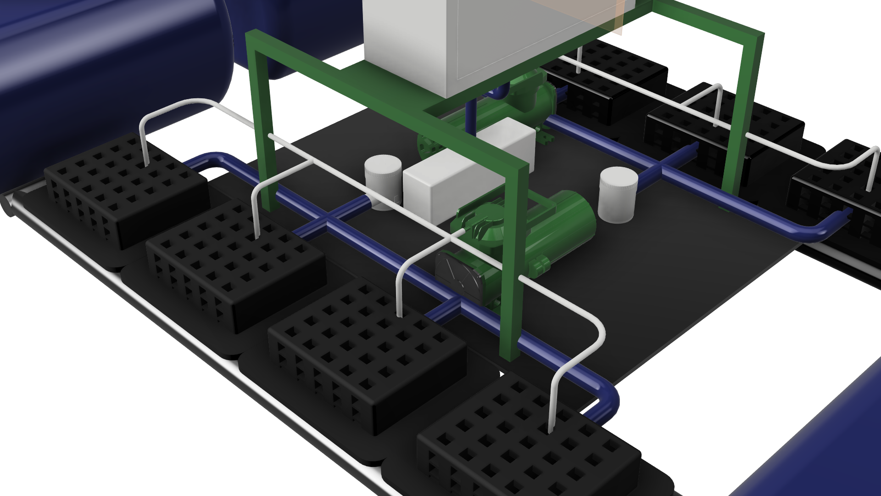
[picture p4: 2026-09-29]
model/SmartCrabAeration4.png

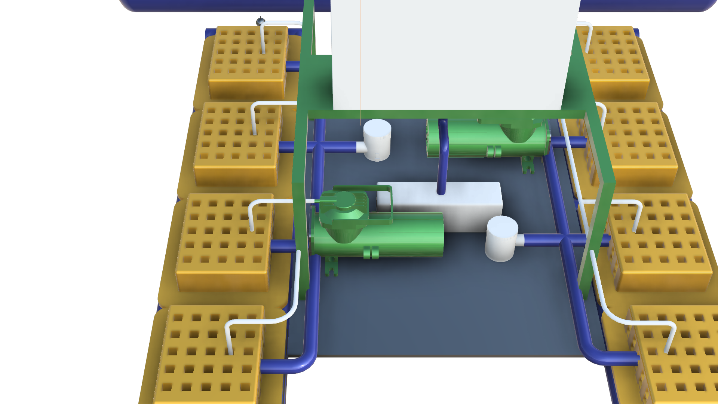
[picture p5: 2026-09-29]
model/SmartCrabAeration9.png

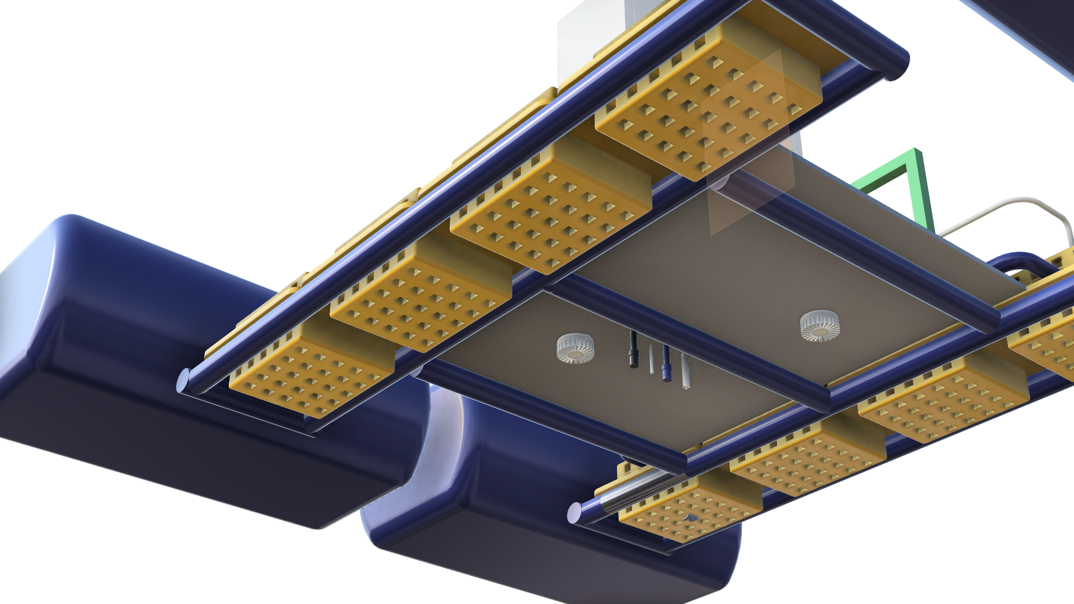
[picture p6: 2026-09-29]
model/SmartCrabAeration6.png

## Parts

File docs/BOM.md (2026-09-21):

# BOM — Solar Automated LoRa-Integrated Mud Crab Aeration Network with Crab Grid Observation

---

## 1. Boards & Connectivity

| # | Item | Qty | Est. Price | Rating (verified) | URL | Why compatible |
|---|---|-----|---|---|-----|---|
| 1 | **ESP32 DevKit, 38-pin (ESP32-WROOM-32)** — main controller node (float) | 3 (float node + house bridge + spare/dev) | ₱349 ea | Makerlab PH — in stock | [Makerlab: Type-C ESP32 30/38-pin](https://makerlab.ph/search?q=esp32) · alt ₱350: [30/38-pin board](https://makerlab.ph/search?q=esp32) | WiFi+BT MCU reads all analog/digital water sensors; 3.3V logic — sensor boards below output ≤3.4V; WiFi stays OFF on the float. **Pin map avoids all WiFi (ADC2) and boot-strap conflicts — see [Components.md](Components.md) §Controller pin map** |
| 2 | **EBYTE E22-900M22S (SX1262, 915 MHz) LoRa module + 915 MHz antenna (₱100 ea)** — one per node: float, house bridge, spare | 3 | ₱489 ea (verify current listing) | Makerlab PH — search "lora" | [Makerlab: LoRa SX1262](https://makerlab.ph/search?q=lora) · [915 MHz antenna](https://makerlab.ph/search?q=lora) | SPI wiring (SCK 18/MISO 19/MOSI 23/NSS 5, RST 14, **DIO1 26, BUSY 17**) — SX1262 needs a BUSY pin, not DIO0. SX1262 delivers up to +22 dBm on the 915 MHz PH licence-free SRD band. Confirm measured EIRP and NTC type-approval before deployment. **3.3V logic only — never apply 5V to the SPI pins.** Never power without an antenna — instant PA damage. Use **RadioLib**'s SX1262 driver (`sandeepmistry/LoRa` does not support SX126x). |
| 3 | **ESP32-CAM-MB** (OV2640, WiFi/BT) — overhead camera node | 1 | ₱649 | Makerlab PH — in stock | [Makerlab: ESP32-CAM-MB OV2640](https://makerlab.ph/search?q=esp32) | Streams over WiFi only — see **Compatibility Notes #3** |
| 4 | **8-Channel Relay Module, 12V coil, optocoupler** — drives air pumps + bilge pumps | 1 | ₱273 | 4.8 stars (12,201 ratings) | [Shopee listing](https://shopee.ph/DC-12V-8-Channel-Relay-Module-with-Optocoupler-Isolation-PLC-Control-Relay-Output-8-Way-Relay-Module-for-Arduino-i.266699902.19079723116) | **8-ch, not 4-ch**: 2 air pumps + 2 bilge pumps = 4 loads, so a 4-ch board leaves no spare channels for cage valves or a second DO stage; 10A contacts ≥ pump inrush; choose **low-level trigger** for ESP32 3.3V GPIO |

## 2. Water Quality Sensors

| # | Item | Qty | Est. Price | Rating (verified) | URL | Measures |
|---|---|-----|---|---|-----|---|
| 5 | **DFRobot Gravity Analog EC/Salinity Sensor (K=10)** — seawater-range probe | 1 | ₱5,489 | 4.9 stars (DFRobot official store, >1k followers) | [Shopee — DFRobot official](https://shopee.ph/DFRobot-Analog-Electrical-Conductivity-Sensor-Meter-i.18252381.9084450334) · [Datasheet](https://wiki.dfrobot.com/dfr0300-h/) | **Conductivity/salinity** — range **0–100 mS/cm** covers the conductivity around seawater (35 ppt is approximately 53 mS/cm at 25 °C). Use the manufacturer/PSS-78 conversion; do not use a fixed 0.66 ppt-per-mS/cm factor. |
| 6 | **pH Electrode E-201-C + PH-4502C analog board** | 1 | ₱1,395 | 4.9 stars (22 ratings) · probe alone 4.8 stars (53,991) | [Shopee — kit](https://shopee.ph/pH-sensor-PH-4502C-kit-for-Arduino-Analog-Output-E201-BNC-probe-i.64815518.1583999627) · [Shopee — spare probe](https://shopee.ph/pH-Electrode-Sensor-BNC-Connector-Probe-E-201-pH-Composite-electrode-E-201C-i.52451576.28361135684) | **pH** (brackish target 7.5–8.5 per SEAFDEC) |
| 7 | **Waterproof DS18B20 temperature probe (stainless)** | 2 | ₱79 ea | 4.7 stars (3,179 ratings) | [Shopee listing](https://shopee.ph/BEOHESP-DS18B20-Sensor-Stainless-Steel-Waterproof-Temperature-Sensor-1-3-5meters-Probe-Temperature-Probe-i.1231138459.57712308409) | **Temperature** (27–30 °C band; digital 1-Wire, no ADC needed) |
| 8 | **DFRobot Gravity Analog Dissolved Oxygen Kit (SEN0237-A)** | 1 probe | ₱12,000–13,199 | 4.9 stars (53 ratings, DFRobot official store) | [Shopee — DFRobot official](https://shopee.ph/DFRobot-Gravity-Analog-Dissolved-Oxygen-Sensor-Meter-Kit-For-Arduino-i.18252381.2379265111) · [Makerlab PH ₱12,000](https://makerlab.ph/products/gravity-analog-dissolved-oxygen-sensor-meter-kit-for-arduino) | **Dissolved oxygen** — SEAFDEC target **≥ 5 ppm**; DO < 3 ppm is lethal; galvanic probe, no polarization. **One probe only** (single measurement point): mount it on the centred hub at mid-depth, clear of the aerator plume, and provide gentle flow across the membrane. If it drifts or dies, use a handheld DO meter/scheduled aeration and replace the membrane cap (#25). |

> **Targets:** the SEAFDEC/AQD ranges these sensors were chosen against are tabulated in [`Components.md`](Components.md). The one gap is unionized NH₃ (≤ 0.1 ppm) — no affordable sensor exists. pH + temperature can estimate the toxic fraction/risk only; an absolute NH₃ concentration requires measured Total Ammonia Nitrogen (TAN) or a laboratory test. |
>

## 3. Actuators (Aeration + Pumps)

| # | Item | Qty | Est. Price | Rating (verified) | URL | Purpose |
|---|---|-----|---|---|-----|---|
| 9 | **RESUN MPQ-903 (MPQ-03) 12V DC electromagnetic air pump — 35W, 68 L/min, 0.068 MPa, ~3.5A, 6 outlets (aerator path)** | 2 | ~₱1,045 ea | seller-sourced; check rating ≥ 4.7 stars | [Shopee: RESUN 12V air pump MPQ-02/03/04](https://shopee.ph/RESUN-12V-Air-Pump-Electromagnetic-Air-Pump-12volts-MPQ-02-MPQ03-MPQ-04-i.20611812.21445855657) | **Replaced generic 30–60 L/min pick with the verified RESUN MPQ-03 (MPQ-903).** MPQ-03 = **35W, 68 L/min open-flow, 0.068 MPa, ~3.5A, 6 outlets**. Biological target: 1.5–2 L/min per 100 L; 8 cages × ~40 L ≈ 320 L → **about 4.8–6.4 L/min delivered total** (≈0.6–0.8 L/min per cage). One 68 L/min MPQ-03 has huge open-flow headroom to cover depth, tubing and stone losses — so **2 units are for N+1 redundancy, alternating duty**, NOT because each cage needs a full pump. Use a manifold, needle valves and per-branch flow measurement so excess air is not dumped into the cages; 6 outlets each covers the 8 cages across 2 pumps with spares. |
| 10 | **Air stones ×8–10 + 4 mm airline tubing (20 m) + gang valve manifold** | 1 set | ~₱300 | any hardware/pet store | [Shopee search: air stone](https://shopee.ph/search?keyword=air%20stone%20aquarium) | One stone per cage; the manifold balances flow so every cage gets ~2 L/min (the rigid alternative to driving air through the pipe grid, #31) |
| 11 | **12V Marine Bilge Pump 1100 GPH** (submersible) — circulation/flush pump | 2 | ₱649 ea | 4.8 stars (100% chat response) | [Shopee listing](https://shopee.ph/12v-1100gph-Automatic-Submersible-Non-Automatic-Marine-Electric-Bilge-Pump-Submersible-Boat-Bilge-Water-Pump-For-Ponds-Pools-Spas-Silent-Boat-Carav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) · cheaper alt 4.6 stars/294: [₱338](https://shopee.ph/1100GPH-12v-Submersible-Water-Pump-with-Switch-for-Boat-Automatic-Submersible-Small-Boat-Bilge-Pump-i.1768137647.45160954686) | Provides circulation/flushing and can support a controlled salinity experiment. It does not reliably correct salinity in open slotted cages because tidal exchange flushes the dose and dense brine sinks. Use isolation sleeves or a closed-loop/RAS enclosure for a defensible salinity-control test. Verify actual running/inrush current against the relay and branch fuse. |

## 4. Power System (220V AC from Household Solar)

| # | Item | Qty | Est. Price | Rating (verified) | URL | Sizing rationale |
|---|---|-----|---|---|-----|---|
| 12 | **Outdoor-rated 220V AC drop** (3-core, 2.5 mm², earthed; ~30–100 m) | 1 | ₱1,500–2,500 | electrical supply; buy outdoor-rated | [Shopee search: outdoor extension cord](https://shopee.ph/search?keyword=outdoor%20extension%20cord%20heavy%20duty) | Planning estimate: 220V × ~0.5 A ≈ 100 W. A licensed electrician must verify the actual load, conductor ampacity, voltage drop, earthing, connector IP rating and Philippine Electrical Code compliance. Route overhead or in conduit with drip loops; use IP67/IP68 weatherproof terminations and no submerged joints. |
| 13 | **RCD/GFCI 30 mA + 2-pole breaker in a small enclosure** | 1 | ₱800–1,200 | electrical supply | [Shopee search: 30mA RCD breaker](https://shopee.ph/search?keyword=rcd%2030ma%20circuit%20breaker) | **New — mandatory for 220V within reach of water.** Install the 30 mA RCD and breaker at the house/shore end, before the cable reaches the water. Use weatherproof enclosures/connectors, drip loops, no submerged joints, and a monthly test button. Final breaker coordination and conductor/fuse sizing require a licensed electrician. |
| 14 | **12V DC switching PSU, 12V 30 A (360 W)** — replaces panels + MPPT + battery | 1 | ₱600–900 | ≥4.7 stars (thousands of ratings) | [Shopee search: 12V 30A power supply](https://shopee.ph/search?keyword=12v%2030a%20power%20supply) | Planning peak estimate ≈ 140 W worst-case burst (2 × 35 W MPQ-03 + 1 × 30 W bilge + node) ≈ **~12 A**; steady aeration duty is 1 × MPQ-03 (~35 W, ~3 A). Verify every pump nameplate, simultaneous duty, inrush, PSU efficiency and voltage drop before finalizing. Treat 30 A as a provisional supply rating, not proof that a 15 A main fuse is correct; size fuses to the conductors and each branch load. Mount above the waterline in the IP65/66 enclosure (#18, glands #22). |

> **If there is ever no household supply** (pond relocation): add 2 × 100W panels + MPPT 20A + 12V 200Ah LiFePO4 (~₱30,000) — that sizing (600 Wh/night ≈ 50 Ah → 2+ nights) is already validated.
>
> **Check the house inverter before deploying:** it has to stay on 24/7 (an inverter switched off at night means no aeration), be rated well above the ~100 W peak (~300 VA+ is ample, inrush included), and be pure-sine if possible — pump motors run hotter on modified-sine output.
>
> **Single point of failure:** with no on-site battery, a tripped breaker, cut cable or inverter fault stops aeration — a life-support load. Alert on loss-of-heartbeat (no uplink ≈ power or link down) and keep the house-end breaker reachable. A small 12 V battery + charger (~₱3–5k) as a pump-only UPS covers unattended nights.

## 5. Structure & Materials

| # | Item | Qty | Est. Price | Rating (verified) | URL | Notes |
|---|---|-----|---|---|-----|---|
| 15 | **Allied Crab Fattening Box** (individual compartments) | 8 | ₱399 ea = ₱3,192 | 4.7 stars (370 ratings) | [Shopee listing](https://shopee.ph/Allied-Crab-Fattening-Box-Cage-Indoor-Crab-Farming-i.411519694.28807834583) | **Count verified (8) and spec fits:** 457 × 406 × 406 mm holds a 0.5–1.5 kg crab; 1 crab per box = anti-cannibalism; drill slots for water exchange; shade covers needed outdoors (note #6) |
| 16 | **Round plastic shell + solid foam filling 50×90 cm** — 4 units (each supports 2 crab cages) | 4 | ₱2,643 ea = ₱10,572 | 4.9 stars (verified via seller) | [Lazada listing](https://www.lazada.com.ph/products/plastic-floating-platform-i15589282305-s133497781798.html) | **Upgraded from generic foam floats.** Each round float (50 cm dia × 90 cm) has ~326 kg theoretical buoyancy (0.318 m³ × 1,025 kg/m³ brackish), yielding **~163 kg usable** at 2:1 safety factor. Two 50×80×40 cm crab boxes (~44 kg each) fit on one float. Arranged 4 floats × 2 cages each = 8 cages. The pipe grid is conduit only (see §8). |
| 17 | **UV-stabilized PVC/FRP frame preferred; bamboo / marine-plywood alternative + netting + shade cloth** | — | ₱2,000–4,000 | — | [Lazada search: HDPE net](https://www.lazada.com.ph/catalog/?q=hdpe+netting) | Avoid bare plastic in direct sun: the boxes are shaded and stay in water contact. Raw bamboo and ordinary plywood rot/split in a warm brackish mangrove; if retained, seal all faces/end grain with marine epoxy or PU and make contact details replaceable. Specify Grade 316 stainless or nylon fasteners. The air/water pipe grid (#31) rides on this frame. |
| 18 | Misc: waterproof enclosures (IP65/66), cable, epoxy, Grade 316 stainless/nylon fasteners, mooring rope, cable ties | — | ₱2,500–3,500 | — | [Shopee search: IP65 enclosure](https://shopee.ph/search?keyword=ip65%20waterproof%20enclosure) | Electronics must be sealed — brackish mangrove environment. Use Grade 316 stainless or nylon fasteners; 304 stainless can pit in warm chloride-rich water. Air tubing and the gang valve manifold are #10, fuses are #21, and the pipe grid is §8. |

---

## 6. Electrical Protection, Calibration & Consumables

> The items other sections depend on but are easy to forget: the camera's LM2596S 24V/12V → 5V USB step-down module, calibration standards (pH and EC), DO probe membranes, pH electrode storage fluid, and the salt reserve the brine-mixing scenario actually pumps. Ratings verified as described in the header.

| # | Item | Qty | Est. Price | Rating (verified) | URL | Why needed |
|---|---|-----|---|---|-----|---|
| 19 | **LM2596S 24V/12V → 5V USB step-down module (HW-688 / HCW-P715)** — camera node power | 1 | ₱99 | 4.9 stars (715 ratings) · LazMall | [Lazada listing](https://www.lazada.com.ph/products/24v12v-to-5v-usb-mobile-phone-dc-dc-step-down-module-lm2596s-hw-688-hcw-p715-do-not-use-for-raspberry-pi-4-i284590120-s446364184.h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) | Accepts the 12 V supply and provides a 5 V USB output for the ESP32-CAM-MB. Verify the output voltage and polarity before connecting. **Do not use for Raspberry Pi 4.** |
| 21 | **DC blade fuse + holder set** (provisional main/controller/pump ratings) | 1 set | ₱50–150 | check listing; buy ≥ 4.7 stars | [Shopee search: blade fuse holder](https://shopee.ph/search?keyword=blade%20fuse%20holder%20waterproof) | A 12 V supply feeding unprotected pump wiring on a float is a melt/fire risk. Do not finalize the 15 A/5 A/10 A values from estimates: measure running and inrush current, check conductor ampacity and temperature rise, then size one main fuse and per-branch fuses to the protected conductors and loads. |
| 22 | **PG7/IP68 nylon cable glands** (10-pc kit) | 1 kit | ₱78–120 | 4.8 stars (9,383 ratings) | [Shopee listing](https://shopee.ph/Nylon-Cable-Gland-10pcs.-PG7-~-PG63-IP68-Waterproof-Connector-Durable-Plastic-Cable-Fitting-i.1468298505.40724321556) | Item 18 buys the IP65 enclosure but no feedthroughs — sensor/pump cables through plain drilled holes destroy the IP rating |
| 23 | **pH buffer calibration set 4.01 / 6.86 / 9.18** | 1 set | ₱275 | see listing | [Shopee listing](https://shopee.ph/pH-Calibration-Solution-pH-4.01-6.86-9.18-Buffer-for-pH-Meter-Hydroponics-Lab-Professional-Grade-i.911703494.48855977022) | PH-4502C is factory-offset only — 2-point calibration (4.01 + 6.86) is required before any pH reading is meaningful; re-calibrate every 2–4 weeks |
| 24 | **EC calibration standards: 1.413 mS/cm (1413 µS/cm) + 12.88 mS/cm** | 2 bottles | ~₱300–600 | check listing; buy ≥ 4.7 stars | [Shopee search: EC 1.413 mS/cm solution](https://shopee.ph/search?keyword=ec%20calibration%20solution%201.413) · [Shopee search: EC 12.88 mS/cm solution](https://shopee.ph/search?keyword=ec%20calibration%20solution%2012.88) | Follow the DFRobot K=10 two-point procedure. 12.88 mS/cm is a conductivity calibration standard, not 35 ppt seawater; convert calibrated EC to salinity with the manufacturer/PSS-78 method. |
| 25 | **DO probe spare membrane caps + electrolyte refill** (SEN0237-A consumables) | 1 kit | ~₱500–1,000 | check DFRobot store | [DFRobot wiki (maintenance)](https://wiki.dfrobot.com/sen0237-a/) · [Shopee search](https://shopee.ph/search?keyword=dissolved%20oxygen%20probe%20membrane) | Galvanic DO probes consume membrane caps + electrolyte — without spares the ₱12k sensor goes dead mid-project. Calibrate in water-saturated air (single point) before each deployment, with only one probe a failed membrane means losing the DO trigger until it is replaced |
| 26 | **pH electrode storage solution (KCl)** | 1 bottle | ~₱150–300 | check listing; buy ≥ 4.7 stars | [Shopee search: KCl storage solution](https://shopee.ph/search?keyword=ph%20electrode%20storage%20solution%20kcl) | The E-201-C electrode dies in weeks if stored dry or in distilled water — KCl storage is what makes the ₱1,395 probe last the project |
| 27 | **Handheld salinity refractometer 0–100 ppt, ATC** | 1 | ~₱500–800 | 4.7 stars (47,728 ratings) | [Shopee listing](https://shopee.ph/Salinity-Refractometer-For-Seawater-And-Marine-Fishkeeping-Aquarium-0-100-Ppt-With-Automatic-Temperature-Compensation-i.119376804.27414109823) | Ground-truth cross-check for the EC sensor during calibration and for verifying brine mixing after rain events — no power needed |
| 28 | **Brine reserve for a controlled salinity experiment only: rock/feed-grade salt ~25 kg + sealed 100–120 L drum** | 1 set | ~₱1,400–1,700 | check listing | [Shopee search: rock salt](https://shopee.ph/search?keyword=rock%20salt%20feed%20grade) | 25 kg salt can make roughly 90 L of saturated brine (about 26 wt%) under typical conditions. Do not present dosing into open slotted cages as reliable salinity correction: tidal flushing and density-driven sinking will remove the dose. Use temporary isolation sleeves or a closed-loop/RAS enclosure, and log tide/current plus pre/post salinity at multiple points. |

> Dev-time only (not system hardware): a USB-TTL adapter (~₱80) to flash the ESP32-CAM-MB if you don't already own one.

---

## 7. Control Interface (Manual + Automatic)

| # | Item | Qty | Est. Price | Rating (verified) | URL | Why needed |
|---|---|-----|---|---|-----|---|
| 29 | **3-position rotary selector (AUTO / OFF / MANUAL)** + knob + panel label | 1 | ₱150–300 | electrical supply | [Shopee search: rotary selector switch](https://shopee.ph/search?keyword=rotary%20selector%20switch%203%20position) | Local fail-safe mode switch — readable at a glance and works with no internet, bridge node or phone. Wires to 2 GPIO inputs with debounce in firmware |
| 30 | **Status LEDs (mode + pump running) + resistors** | 1 set | ₱50–100 | hardware supply | [Shopee search: 5mm LED assortment](https://shopee.ph/search?keyword=5mm%20led%20assorted%20resistor) | Shows the *actual* relay state at the box: which mode is latched and which pump is energised, without opening the dashboard |

**Mode logic (firmware):** AUTO on boot, reset or link loss with aeration ON · MANUAL auto-reverts to AUTO after 5 min without a command · DO below 3 ppm overrides MANUAL and forces aeration on · mode and pump state echoed in every uplink. **Downlink payload (2 bytes, wrapped by the full frame in [`FIRMWARE.md`](FIRMWARE.md) §5.2):** byte 0 = mode (0 AUTO, 1 MANUAL, 2 OFF), byte 1 = pump bitmap (air pumps 1/2, bilge 1/2).

**Webapp (free tier):** **Firebase Realtime Database** + Firebase Auth, with Next.js on Vercel — no running cost at this scale, and RTDB's JSON tree with `onValue()` listeners suits live telemetry better than a document store here. Keep live state in one node (`devices/<id>/state`) for the UI and append history under a trimmed `logs/<id>/<timestamp>` path, or export CSV, so data to chart. Server env vars: `FIREBASE_DATABASE_URL`, `FIREBASE_PROJECT_ID`, `FIREBASE_CLIENT_EMAIL`, `FIREBASE_PRIVATE_KEY`.

---

## 8. Distribution Network & Sensor Hub

| # | Item | Qty | Est. Price | Rating (verified) | URL | Why needed |
|---|---|-----|---|---|-----|---|
| 31 | **PVC pipe network, 25 mm (1")** — pipe, tees, elbows, reducers, end caps, 8 × 6–8 mm per-cage outlets + small valves | 1 set | ₱1,500–3,000 | hardware supply | [Shopee search: PVC pipe fittings](https://shopee.ph/search?keyword=pvc%20pipe%20fittings%201%20inch) | Doubles as the air header (drop tubes and stones are #10) and as the water header fed by the bilge pumps. Split the grid into two halves — one per bilge pump — for balanced flow, and add flush ports for salt and algae |
| 32 | **Flexible hose, 10–12 mm, ~20 m** (pump → per-cage outlet) | 1 set | ₱500–1,000 | hardware supply | [Shopee search: vinyl hose 12mm](https://shopee.ph/search?keyword=vinyl%20hose%2012mm) | The flexible alternative to rigid runs: easier to reposition per cage and to spot a blockage |
| 33 | **Sensor hub** — probe holder/bracket, slotted PVC or plastic cage, stainless bolts, cable ties | 1 set | ₱300–800 | hardware supply | [Shopee search: stainless bolts cable ties](https://shopee.ph/search?keyword=stainless%20bolts%20cable%20ties) | Holds the EC/pH/DO/temp probes in one centred, removable cluster at mid-depth — pull it out for calibration and cleaning |

---

## Compatibility Verification (system-level)

| # | Check | Verdict |
|---|---|---|
| 1 | **LoRa band / regulatory status** | 915 MHz (E22-900M22S / SX1262) — the Philippine NTC licence-free SRD band for low-duty telemetry; both ends on the same band/freq/SF. Confirm maximum EIRP and type-approval before deployment. No TTN/ChirpStack — the dashboard talks to the **house bridge node** over WiFi. |
| 2 | **Voltage chain and mains safety** | 220V AC (household solar, 24/7) → shore-end 30 mA RCD + breaker (#13) → weatherproof feedthroughs → **12V 30 A PSU (#14)** → 12V pumps/relays directly; LM2596S 24V/12V → 5V USB step-down module (#19) for the camera node and the ESP32 DevKit 5V pin (onboard 3.3 V LDO feeds the E22-900M22S — never at 5V). No on-site panel/MPPT/battery. Licensed-electrician installation, PEC review, IP67/IP68 connectors, drip loops, no submerged joints, monthly RCD test, and measured fuse/conductor coordination are deployment gates. |
| 3 | **Camera connectivity** | ESP32-CAM-MB uses **WiFi, not LoRa** (video can't fit LoRa bandwidth). Options: (a) farmer connects phone to camera AP during pond visits, (b) put camera at the house with the bridge node where WiFi exists, (c) upgrade to an LTE camera — budget decision for the panel |
| 4 | **Ammonia sensing gap** | No affordable verified NH₃ sensor on Shopee. Industry option: DFRobot RS485 NH₄⁺ sensor (~$209 / ~₱12k, [dfrobot.com](https://www.dfrobot.com/blog-20760.html)). **Workaround:** pH + temperature can estimate the toxic fraction/risk only; an absolute NH₃ concentration requires measured Total Ammonia Nitrogen (TAN) or a laboratory test. |
| 5 | **Sensor ADC levels** | PH-4502C outputs up to ~5V with 2.5V offset → use 10 kΩ series + 18 kΩ shunt (5 V → about 3.21 V) or an ADS1115 I2C ADC with 3.3 V level shifting. DFRobot EC/DO boards output ≤3.4V → direct |
| 6 | **Overheating** | Boxes are shaded under the frame and stay in water contact; frame/gantry surfaces are non-plastic, so no bare plastic sits in direct sun |
| 7 | **Load vs. relay & supply** | Bilge 3–5A, MPQ-03 air pump ~3.5A each — all ≤ 10A per relay channel; 8-ch module covers all loads + spares. Peak ≈ 2×air(7A) + 1×bilge(~5A) + node = ~13 A worst-case burst at 12 V (~3.5×30 A PSU, and contacts comfortably inside the 10 A relay rating). |
| 8 | **Aeration capacity** | 8 cages ≈ 320 L total → target approximately 4.8–6.4 L/min delivered (1.5–2 L/min per 100 L). Each MPQ-03 is rated 68 L/min open-flow at 35W, so 2 units give N+1 redundancy and alternating duty, not because each cage needs a full pump. Use valves/manifolds and measure each branch. |
| 9 | **Buoyancy** | Use manufacturer-rated foam-filled pontoons (target ≥50 kg each), but size them from the measured dry above-water load and load distribution. Water inside a slotted submerged cage is not a dead load; physically load-test the assembled grid and apply at least a 2:1 safety factor. Hollow PVC is not primary flotation. |
| 10 | **Night operation (life-support, doc requirement)** | Planning draw ~50–60 W (≈ 5 A at 12 V), but verify actual duty cycle, inverter efficiency and battery usable capacity. The house bank must stay on 24/7. No on-site battery → alert on heartbeat loss; add a small UPS/supercapacitor only if last-gasp telemetry or unattended-night runtime is required. |
| 11 | **Control path** | AUTO is the default with a local selector as fail-safe (§7); MANUAL auto-reverts after 5 minutes. Normal command latency may be one uplink interval (5–15 min), but emergency sensor events must transmit immediately. Use device ID, sequence, CRC-8, expiry and ACK/NAK. |
| 12 | **Distribution & buoyancy** | Separate air and water circuits in the pipe grid with the air kept above the waterline, per-cage valved outlets and flush ports (§8); water-filled pipe (~1 kg/L) still inside the 2:1 buoyancy factor |
| 13 | **ESP32 pin conflicts (WiFi + boot)** | **Validated — [Components.md](Components.md) §Controller pin map.** No analog on ADC2 while WiFi runs: all three analog sensors on **ADC1** (34/35/36). GPIO 4/21 selector inputs and used relay inputs need external 10 kΩ pull-ups in the marine enclosure. No loads on boot-strap pins (0/2/5/12/15): NSS=5 idles HIGH, RST=14 glitch is a harmless radio reset, GPIO 0/12/15 left unconnected. UART0 (1/3) free for flashing. Relays are low-level trigger → drive HIGH before init and confirm the module's input pull-up behavior. |

## Power Budget (validated)

| Load | Watts | Duty | Wh/day |
|---|---|---|---|
| ESP32 + E22-900M22S controller node | ~1.5 | 24 h | 36 |
| Air pumps (RESUN MPQ-03, 35W each; 1 duty / 1 N+1 standby) | ~35–70 | 16–24 h (incl. night) | ~560–840 worst case |
| Bilge pumps (salinity events) | ~60 | intermittent (~1 h/day avg) | ~60 |
| House bridge node (ESP32 + E22-900M22S, at house w/ mains) | ~1.5 | 24 h | 0 (house supply) |
| ESP32-CAM-MB node | ~1.5 | visits only | ~10 |
| **Total on-site DC load** | | | **≈ 430–700 Wh/day** |
| **On-site supply: 12V 30 A PSU (#14)** | 360 W | — | peak ≈ 100 W ≈ 8.4 A → ~3.5× headroom for inrush |
| **Supply: household solar → 220V AC** | array + **> 600 Ah** bank + inverter | 24/7 | ≈ 5.8 kWh usable vs ~0.6 kWh/night → **~8–10× margin** |
| **Night draw (life-support)** | ~50–60 W ≈ **5 A @ 12 V** | 12 h | **≈ 600 Wh** — supplied by the house bank; inverter adds ~15% on the AC side |

## Budget Summary

| Category | Est. Cost |
|---|---|
| Boards & connectivity (3× ESP32, 3× E22-900M22S+antenna, ESP32-CAM-MB, 8-ch relay) | ₱3,436 |
| Sensors (Tier 1: EC + 2× DS18B20 → full set incl. pH + DO) | ₱5,647 → ₱19,042–20,241 |
| Aeration + pumps (2× RESUN MPQ-03 air pumps, air stones/manifold, 2× bilge) | ₱3,688 |
| Power — AC drop + protection + 12V supply (outdoor AC run, RCD/breaker, 12V 30 A PSU) | ₱2,900–4,600 |
|| Structure & materials (boxes ×8, 4× round floats 50×90, frame, misc) | ₱15,764–21,264 |
| Protection, calibration & consumables (§6: LM2596S module, fuses, glands, buffers, EC standards, DO membranes, KCl, refractometer, brine reserve) | ₱3,352–5,044 |
| Control interface (§7: AUTO/OFF/MANUAL selector + status LEDs) | ₱200–400 |
| Distribution & sensor hub (§8: PVC air/water grid, per-cage outlets, hose, probe holder) | ₱2,300–4,800 |
| **TOTAL (Tier 1 sensors)** | **≈ ₱39,787–48,879** |
| **TOTAL (all sensors)** | **≈ ₱53,182–63,473** |

---

## GRAND TOTAL SUMMARY

| Build Configuration | Low Estimate | High Estimate |
|---|---|---|
| **Tier 1 Sensors (EC + Temp only)** | **₱39,787** | **₱48,879** |
| **Full Sensor Set (EC + pH + DO + Temp)** | **₱53,182** | **₱63,473** |
| ₱50K Cap (Cuts 1–2: No camera, no DO) | **₱39,934** | **₱48,526** |
| Minimum Viable (Cuts 1–5: No cam, DO, spare, 2nd pump, pH) | **₱36,777** | **₱45,369** |

### Quick Reference: What's Inside Each Total

| Tier | Sensors Included | Actuators | Power | Structure | Est. Range |
|---|---|---|---|---|---|
| Tier 1 | EC (#5) + 2× Temp (#7) | 2× air pump, 1× bilge, relay | AC drop, RCD, 12V PSU | 8 boxes, 4× round floats 50×90, frame | ₱39,787–48,879 |
| Full Set | EC + pH (#6) + DO (#8) + Temp | 2× air pump, 2× bilge, relay | AC drop, RCD, 12V PSU | 8 boxes, 4× round floats 50×90, frame | ₱53,182–63,473 |
| ₱50K Cap | EC + Temp only | 2× air pump, 1× bilge, relay | AC drop, RCD, 12V PSU | 8 boxes, 4× round floats 50×90, frame | ₱39,934–48,526 |
| Min Viable | EC + Temp only | 2× air pump, 1× bilge (cheaper), relay | AC drop, RCD, 12V PSU | 8 boxes, 4× round floats 50×90, basic frame | ₱36,777–45,369 |

> **Note:** All totals exclude the webapp (₱0 on Firebase Spark + Vercel Hobby free tiers). Sourcing at low-end listings keeps costs down; always verify current prices before ordering.

---

## Budget Notes
>
> **₱50,000 hardware ceiling:** the camera (#3) and its LM2596S module (#19) are the designated first cut (₱748) if the build runs over — it is the only optional subsystem. The DO kit (₱12–13k) is what pushes the full set past the ceiling, so it belongs in the last phase; the DO probe and the aerators are never cut.
>
> **Where the money actually goes:** solar generation costs ₱0 here — the household already supplies it, so the power category is only the AC drop, its protection and the 12 V supply (₱2,900–4,600). Two items now dominate: the DO kit (#8) at ₱12,000–13,199 and the EC sensor (#5) at ₱5,489 — together ₱17,500–18,700. The old #1 spend, the LoRaWAN gateway (₱10,645), is gone: the entire radio stack (3 × ESP32 + E22-900M22S + antenna) now costs ~₱2,500. The high end of every range assumes the most expensive listing; the low ends are real listings linked in each row.

> **Which items belong to which phase** (per-phase costs are in the README's BOM & Budget section): (1) bench — ESP32 ×2 (#1) + E22-900M22S/antenna ×2 (#2) — the float node plus a bench partner node — DS18B20 (#7), relay module (#4), one bilge pump (#11), selector + LEDs (#29–30) · (2) dashboard — house bridge node (1 × ESP32 #1 + E22-900M22S/antenna #2), EC sensor (#5), refractometer (#27), EC standards (#24) · (3) power to the float — AC drop (#12), RCD (#13), 12V 30A PSU (#14), LM2596S module (#19), fuses (#21), glands (#22) · (4) full feature set — DO (#8), pH (#6) + buffers (#23), camera (#3), second bilge pump (#11), boxes (#15), frame + netting + shade (#17), pontoons (#16), misc hardware (#18), pipe grid + hose + sensor hub (#31–33), air pumps and stones (#9–10), brine reserve (#28), DO membranes (#25), KCl (#26).
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

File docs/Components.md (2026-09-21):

# Components List

**Project:** Solar Automated LoRa-Integrated Mud Crab Aeration Network with Crab Grid Observation

> Every count and specification below was **validated against web sources on Sept 2026** — SEAFDEC/AQD (Philippines) mud crab culture standards, FAO mud crab manual, DFRobot sensor datasheets, and Shopee/Lazada PH listings. Rationale for each correction is stated inline; see [`BOM.md`](BOM.md) for the verified product links.

---

## Physical Structure

| Component | Spec / Count | Validated? | Purpose / Notes |
|---|---|---|---|
| Floating Cages | **8 × individual crab fattening boxes** (plastic, with slots/holes for water exchange) | Correct count | 1 crab per box = anti-cannibalism, matching commercial practice (individual boxes/cages are the standard mud crab fattening method). Mud crabs tolerate crowding **in water** — the constraint is separation, not volume, so 8 units is adequate for a 500 sqm prototype. |
| Cage size (target) | ≥ 45 × 40 × 35 cm water-filled, e.g. Allied box (457 × 406 × 406 mm) | Sized | Holds a 0.5–1.5 kg fattening crab without contact with hot plastic walls; FAO/industry boxes range from 31 × 26 × 10 cm up to 458 × 406 × 354 mm. |
| Floaters | **Ready-made foam-filled pontoon floats** (HDPE/LLDPE shell, one-piece foam-filled) — **8–12 units**, NOT hollow PVC pipes | **Corrected** | Size pontoons from the measured dry above-water load, not from the weight of water inside a slotted submerged cage. Water in a slotted cage is continuous with the estuary and is not a dead load while submerged; the crab and plastic have their own buoyancy. Use manufacturer-rated floats (target ≥50 kg each), verify the actual box/frame dry mass and load distribution, then apply at least a 2:1 safety factor. A sealed hollow 4″ PVC pipe gives only ~2.6 kg/m and is not primary flotation. The pipe grid is **conduit only, never flotation** — water-filled pipe adds ~1 kg per litre and must be included in the dry/wet load test. |
| Cage frames / gantry | UV-stabilized PVC/FRP preferred; bamboo or marine plywood only with marine-grade sealing | **Material correction** | Raw bamboo and ordinary plywood rot, split, and attract marine borers in a warm brackish mangrove. If wood is retained, seal all faces and end grain with marine epoxy/PU, keep sacrificial contact details replaceable, and specify Grade 316 stainless or nylon fasteners. |
| Air / water routing | **The PVC pipe grid is the distribution network**: a separate air header (drop tube + stone per cage) and a water header fed by the bilge pumps (valved outlet per cage); flexible hose runs pump→cage as an option/backup | **Never one lumen for both** — water floods an air line and kills aeration, while air pockets choke water flow. Keep the air circuit above the waterline or add a drip loop. A 25 mm (1") header with 8 × 6–8 mm outlets balances flow; split the grid in two, one half per bilge pump. Add flush ports — salt and algae will settle in the runs. |
| Sensor hub | Probe cluster **centred on the grid**, holding EC/pH/DO/2× DS18B20 at mid-depth (~20–30 cm below the surface) | Centred = balanced float load and symmetric cable runs. Mid-depth readings are representative: the surface is skewed by aeration and sun, the bottom by sludge and salinity stratification. Keep it clear of the aerator plume, provide gentle flow across the DO membrane before readings, and make it removable for calibration. One DO probe remains a single-point risk. |
| Water circulation | Air-driven through the pipe grid, plus controlled circulation/flushing through the water header | **Scope correction** | Bubbling creates movement inside each cage; the valved outlets let the circulation pumps flush or mix a test volume. Reliable salinity correction is not claimed for open slotted cages because tidal flushing and dense brine sinking defeat dosing. Use temporary isolation sleeves or a closed-loop/RAS test if salinity control is an objective. |

## Electronics & Hardware

| Component | Spec / Count | Validated? | Purpose / Notes |
|---|---|---|---|
| Controller | **ESP32 DevKit (38-pin, ESP32-WROOM-32) + EBYTE E22-900M22S (SX1262, 915 MHz)**, centred in the setup, IP65 enclosure | OK with compliance gate | Runs automation logic; links sensors, pumps, and the LoRa point-to-point link. WiFi stays off on the float. Budget pick over the Heltec V3: ~₱740/node (board + module + antenna) instead of ₱1,974, and the pin map below avoids every WiFi/boot conflict. 915 MHz is the Philippine NTC licence-free SRD band; confirm EIRP/type-approval before deployment. |
| Water Quality Sensors | 4 sensor types: EC/salinity (K=10), pH, dissolved oxygen (**one probe**), temperature (2× DS18B20 probes) | Validated ranges with limits | **EC K=10 (0–100 mS/cm)** covers the conductivity range around seawater (35 ppt is approximately 53 mS/cm at 25 °C), but salinity must use the manufacturer/PSS-78 conversion, not a fixed linear ppt factor. **pH E-201-C** covers the 7.5–8.5 brackish target. **DO galvanic probe (SEN0237-A)** supports the ≥5 ppm target, but one probe is a single-point failure; provide flow across the membrane, a handheld backup, and spare membrane/electrolyte. DS18B20 covers the 27–30 °C band. |
| LoRa ⇄ WiFi Bridge | **A second ESP32 DevKit + E22-900M22S (915 MHz) at the house** where WiFi/internet exists — the "bridge node" | **Replaced LoRaWAN gateway (Sept 2026)** | The ₱10,645 LoRaWAN gateway is gone. The bridge receives float uplinks and pushes them into the Firebase webapp; queued commands are pulled from the webapp and sent back down over LoRa — plain point-to-point radio, no TTN/ChirpStack server. SX1262 delivers up to +22 dBm on the 915 MHz SRD band. The 1–3 km LOS estimate is a test target, not a regulatory guarantee; confirm NTC type-approval and measured EIRP before deployment. |
| Aerator | **2 × RESUN MPQ-903 (MPQ-03) 12V DC electromagnetic air pump — 35W, 68 L/min open-flow, 0.068 MPa, ~3.5A, 6 outlets** (NOT 2× mini aquarium pumps) | **Corrected** | Mini pumps (~0.5–2 L/min each) cannot aerate 8 cages. The biological target is 1.5–2 L/min per 100 L, so 8 cages × ~40 L ≈ 320 L needs about **4.8–6.4 L/min delivered total** (roughly 0.6–0.8 L/min per cage). The 68 L/min MPQ-03 is deliberately far above the target to cover depth, tubing and stone losses; run ONE unit on duty with the second on N+1 standby (alternating duty), and use a manifold, needle valves and per-branch flow measurement so excess air is not dumped into the cages. |
| Air stones / tubing | 8–10 × air stones + 20 m 4 mm silicone tubing + gang valve manifold | Added | Distributes air from the 2 pumps into each of the 8 cages. |
| Circulation / Flush Pump | **2 × 12V Marine Bilge Pump 1100 GPH** (submersible) | **Function corrected** | Provides circulation/flushing and can support a controlled salinity experiment. It does not reliably correct salinity in open slotted cages because tidal exchange flushes the dose and dense brine sinks. Use isolation sleeves or a closed-loop/RAS enclosure for a defensible salinity-control test; verify pump current against the relay and fuse rating. |
| Relay Module | **8-channel**, 12V coil, optocoupler, low-level trigger | Chosen | 2 air pumps + 2 bilge pumps = 4 loads, so a 4-ch board would leave zero expansion; 8-ch covers every actuator path plus spares. |
| Camera | Overhead, one unit initially (optional, ESP32-CAM-MB) — **first thing to cut if the build passes ₱50,000** | OK | Monitor molting, deter predators, spot poachers. WiFi-only — see BOM Compatibility #3. |
| Control Interface | **Local rotary selector (AUTO / OFF / MANUAL)** + status LEDs at the controller box, plus webapp control | The LoRa link is polled point-to-point — a command lands only on the next uplink — so a local selector is the fail-safe for a life-support load. Mode and pump state are echoed in every uplink. |
| Dashboard / Webapp | **Next.js + Firebase Realtime Database + Auth**, free-tier hosting (Vercel) | Live readings, AUTO/MANUAL/OFF, per-pump overrides, thresholds. RTDB's `onValue()` sync is a natural fit for telemetry: keep live state in one node and trim the history log so it stays inside the free tier. |
| Power Source | **220V AC drop from the household solar system** (array + battery bank **> 600 Ah** + inverter, available 24/7) + **12V 30 A DC supply** on the float | **Corrected** | The site already sits on a household solar installation with a battery bank over 600 Ah, so panels, MPPT and an on-site battery are unnecessary. Night aeration is a planning estimate of 1 × MPQ-03 (35 W) on duty + node 1.5 W + bilge duty ≈ 40–60 W ≈ **480–720 Wh/night ≈ 3.5–5 A at 12V**; verify inverter efficiency and actual duty cycle. On-site work is only a shore-end 30 mA RCD + earthed outdoor AC run + 12V 30 A PSU (see BOM §4), installed and commissioned by a licensed electrician. With no on-site battery, the AC drop is the single point of failure; the house bridge must alarm on heartbeat loss. |

### Controller pin map — ESP32 38-pin DevKit (WiFi/boot-safe)

> Validated for the ESP32-WROOM-32 DevKit (Makerlab PH, ₱349). Rules: **no analog on ADC2** (GPIO 0/2/4/13/14/15/25/26/27 stop working as analog while WiFi runs), **no actuators on boot-strapping pins** (GPIO 0, 2, 12 and 15 glitch or break boot; 5 is usable only for outputs that idle HIGH, which the radio NSS below does), **UART0 (GPIO 1/3) kept free** for flashing and logs. The float node never enables WiFi and the house bridge reads no analog, but the map is safe under both configurations.

| Function | GPIO | Why it's safe |
|---|---|---|
| LoRa E22-900M22S SCK / MISO / MOSI | 18 / 19 / 23 | Hardware VSPI — independent of WiFi |
| LoRa E22-900M22S NSS | 5 | Boot-strapping pin, but NSS **idles HIGH (radio deselected)** — safe at boot |
| LoRa E22-900M22S RST | 14 | Driven after boot; the brief boot-time PWM glitch just resets the radio harmlessly |
| LoRa E22-900M22S DIO1 (IRQ) | 26 | SX1262 signals RX/TX-done on DIO1 (not DIO0); idle LOW at boot, no strapping role; GPIO 26 is ADC2-capable but used as a digital IRQ |
| LoRa E22-900M22S BUSY | 17 | SX1262 requires a BUSY line (not present on SX127x); GPIO 17 is a free digital pin (ADC2-capable, digital-only) |
| DS18B20 ×2 (shared 1-Wire bus) | 16 | Free digital pin; external 4.7 kΩ pull-up to 3.3 V |
| pH analog output (via 10 kΩ series + 18 kΩ shunt divider, or ADS1115) | 34 | **ADC1** — works with WiFi on; input-only pin. 5 V → about 3.21 V with the passive divider; use a common ground and, preferably, an external 16-bit I2C ADC for professional-grade pH. |
| EC/salinity analog output | 35 | **ADC1** — input-only |
| DO sensor analog output | 36 (VP) | **ADC1** — input-only |

| Relay 1 — air pump 1 | 25 | Non-strapping output; firmware drives HIGH (relay OFF) before init |
| Relay 2 — air pump 2 | 27 | Same (digital output — the ADC2 restriction affects analog reads only) |
| Relay 3 — bilge pump 1 | 33 | Non-strapping output; same boot practice |
| Relay 4 — bilge pump 2 | 13 | ADC2 pin, but only its **analog** function is WiFi-blocked — digital output is unaffected |
| Rotary selector bit A (AUTO/MANUAL) | 4 | Input with external 10 kΩ pull-up to 3.3 V; selector shorts to GND. GPIO 4 is ADC2-capable but is used only as a digital input. |
| Rotary selector bit B (AUTO/OFF) | 21 | Input with external 10 kΩ pull-up to 3.3 V; selector shorts to GND. |
| Mode LED (external) | 22 | Output |
| Link/status LED | 2 (onboard LED) | The devkit's boot LED doubles as the link indicator |

**Leave unconnected:** GPIO 0 (boot strapping — low at reset = flash mode), GPIO 12 (HIGH at boot = flash-voltage fault → boot failure), GPIO 15 (boot strapping), GPIO 1/3 (USB serial). Relay modules are low-level trigger: drive the GPIO HIGH before initializing the pins, keep the relay off at boot, and add an external 10 kΩ pull-up to 3.3 V on each used relay input if the module does not already provide a reliable pull-up. The house bridge reuses the same SPI wiring (18/19/23/5) plus DIO1 26 and BUSY 17.

---

## Validated Water-Quality Targets (deployment reference)

From **SEAFDEC/AQD (Philippines)** mud crab culture standards:

| Parameter | Target / Safe Range | Sensor |
|---|---|---|
| Dissolved Oxygen | **≥ 5 ppm** | DFRobot SEN0237-A galvanic DO probe |
| Salinity | **28–32 ppt** (grow-out tolerates 10–34 ppt) | DFRobot EC K=10 (0–100 mS/cm); convert with the manufacturer/PSS-78 method. At 25 °C, 35 ppt seawater is approximately 53 mS/cm; do not treat 12.88 mS/cm as 35 ppt. |
| Temperature | **27–30 °C** | 2× DS18B20 stainless waterproof probes |
| pH | **7.5–8.5** | E-201-C electrode + PH-4502C board |
| NH₃ (unionized) | **Cannot be calculated from pH + temperature alone**. pH + temperature estimate the toxic fraction/risk; absolute NH₃ requires measured Total Ammonia Nitrogen (TAN) or a laboratory test. | derived risk indicator only |

## Deployment Corrections and Verification Gates

1. **Buoyancy:** weigh the empty boxes, frame, pumps, electronics and water-retaining pipes; measure the actual float rating and load distribution. Do not use the weight of water inside a slotted submerged cage as a pontoon load. Apply at least a 2:1 safety factor and physically load-test the assembled grid before stocking.
2. **Aeration:** the MPQ-03's 68 L/min rating is open-flow, not guaranteed delivered flow. Measure each branch at operating depth with air stones installed; target approximately 4.8–6.4 L/min total for 320 L and regulate excess flow.
3. **Salinity:** an open slotted cage is hydraulically connected to the estuary. Brine dosing is a controlled experiment only unless the cage is temporarily isolated or the test is closed-loop. Record tide, current, dose, and pre/post salinity at multiple points.
4. **Electrical:** the 220 V AC drop is a licensed-electrician installation. Require shore-end 30 mA RCD protection, weatherproof connectors, drip loops, no submerged joints, conductor/fuse coordination, earthing verification, and a monthly RCD test.
6. **Protocol:** use device ID, sequence number, CRC-8, expiry, ACK/NAK, a 60-second heartbeat, and immediate emergency uplinks for DO or other critical thresholds.

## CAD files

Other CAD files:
model/SmartCrabAeration.f3d

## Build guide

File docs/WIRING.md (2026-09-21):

# Wiring and Assembly Guide

**Project:** Solar Automated LoRa-Integrated Mud Crab Aeration Network with Crab Grid Observation

This document is the physical build reference: assembly order, the verified ESP32 38-pin pin map (WiFi- and boot-safe), subsystem wiring tables, and the pre-energize checklist. Electrical ratings and product links live in [`HARDWARE.md`](HARDWARE.md) and [`BOM.md`](BOM.md).

## Wiring Project Files

| File | Description |
|---|---|
| [`wiring/Smart Crab Aeration.ckt`](../wiring/Smart Crab Aeration.ckt) | CirKit Designer project file (editable schematic) |
| [`wiring/circuit_image.png`](../wiring/circuit_image.png) | Circuit diagram export |
| [CirKit Designer Web](https://app.cirkitdesigner.com/project/8bfbd974-cd46-45d2-8940-42625b01e279) | View/edit online |

## 1. Safety Gates

1. The 220 V AC drop, RCD/breaker, and earthing are installed and commissioned by a **licensed electrician** (Philippine Electrical Code). Builders work on 12 V DC only.
2. Never power a LoRa node without its **antenna** attached — instant PA damage.
3. Weatherproof everything: IP65/66 enclosures, IP68 cable glands, drip loops, **no submerged joints**.
4. Never test pumps in a pond with crabs stocked; use buckets on the bench.

## 2. Assembly Order

| Step | Task | Reference |
|---|---|---|
| 1 | Bench-assemble the controller node: ESP32 + E22 on jumper wires first, verify uplink with a second node | [`TESTING.md`](TESTING.md) LNK-01 |
| 2 | Wire the relay module and selector on the bench; verify the three positions decode correctly | §5, §6 below |
| 3 | Mount ESP32, relay module, PSU area, and fuse box inside the IP65 enclosure; glands for every cable exit | §7 |
| 4 | Build the pontoon grid: 4 round foam floats (50 × 90 cm), frame/gantry, 8 slotted fattening boxes, shading | [`Components.md`](Components.md) — Physical Structure |
| 5 | Lay the PVC air header and water header as **separate circuits**; air circuit above the waterline or drip-looped | [`Components.md`](Components.md) — Air/water routing |
| 6 | Build the sensor hub: centred, removable probe cluster at mid-depth (~20–30 cm) | [`Components.md`](Components.md) — Sensor hub |
| 7 | Electrician: shore-end 30 mA RCD + 2-pole breaker, earthed 2.5 mm² outdoor run to the float | §8 |
| 8 | Commissioning: rails check, calibration, then the [`TESTING.md`](TESTING.md) matrix | — |

## 3. Verified ESP32 38-Pin Pin Map (float node)

Every pin below was checked against the three ESP32-WROOM-32 constraint classes: **ADC2 pins lose analog function while WiFi runs**, **boot-strapping pins (0, 2, 5, 12, 15) must not be loaded at reset**, and **UART0 (1, 3) must stay free for flashing/logs**. The float node runs WiFi-off, but the map is safe even if WiFi is later enabled, because **all three analog sensors sit on ADC1**.

| Function | GPIO | WiFi/boot verification |
|---|---|---|
| LoRa E22 SCK / MISO / MOSI | 18 / 19 / 23 | Hardware VSPI; independent of WiFi. Safe |
| LoRa E22 NSS | 5 | Strapping pin, but NSS idles HIGH (radio deselected) at reset. Safe |
| LoRa E22 RST | 14 | Driven after boot; the boot-time PWM glitch only resets the radio. Digital-only use |
| LoRa E22 DIO1 (IRQ) | 26 | SX1262 interrupt line; digital use only. Safe |
| LoRa E22 BUSY | 17 | SX1262 mandatory line; plain digital pin. Safe |
| DS18B20 ×2 (shared 1-Wire) | 16 | Free digital pin; external 4.7 kΩ pull-up to 3.3 V |
| pH analog output | 34 | **ADC1** — works with WiFi on; input-only (no internal pull-up: the sensor board drives it) |
| EC/salinity analog output | 35 | **ADC1** — input-only |
| DO analog output | 36 (VP) | **ADC1** — input-only |
| Relay 1 — air pump 1 | 25 | Digital output; ADC2 analog function unused, so WiFi-safe |
| Relay 2 — air pump 2 | 27 | Digital output; same rule |
| Relay 3 — bilge pump 1 | 33 | Digital output; non-strapping. Safe |
| Relay 4 — bilge pump 2 | 13 | Digital output; ADC2 analog unused. Non-strapping. Safe |
| Selector bit A (AUTO/MANUAL) | 4 | Digital input; ADC2 analog unused. External 10 kΩ pull-up, selector shorts to GND |
| Selector bit B (AUTO/OFF) | 21 | Digital input; not an ADC pin. External 10 kΩ pull-up |
| Mode LED | 22 | Output; non-strapping. Safe |
| Link/status LED | 2 | Onboard LED; strapping pin but loaded only after boot by the board itself. Safe as used |
| Spare (input) | 39 (VN) | Input-only, ADC1 — reserved for a future sensor |
| Spare | 32 | ADC1-capable/digital — reserved |

**Deliberately unconnected:** GPIO 0 (boot-mode strap), GPIO 12 (must be LOW at reset — HIGH causes flash-voltage boot failure), GPIO 15 (strap), GPIO 1/3 (UART0 flashing and logs). GPIO 6–11 are internal flash and are not exposed.

**Result: no pin conflicts.** No analog on ADC2, no actuator on a strapping pin, UART0 free, and every relay is a plain digital output.

## 4. Pin-Rule Summary (why the map is conflict-free)

| Rule | How the map complies |
|---|---|
| No analog reads on ADC2 while WiFi runs | All analog sensors on 34/35/36 (ADC1). Pins 4/13/14/25/26/27 are digital-only |
| No loads on boot-strapping pins 0/2/12/15 | 0/12/15 unconnected; 2 carries only the onboard LED after boot |
| GPIO 5 strap tolerance | Used as NSS which idles HIGH — the accepted safe case |
| UART0 free | 1/3 unconnected; logs and flashing unaffected |
| Low-level trigger relays must not chatter at boot | GPIOs are high-Z at reset, so **every used relay input gets an external 10 kΩ pull-up to 3.3 V**; firmware also writes relay pins HIGH before pin init |

## 5. Relay and Actuator Wiring

| Relay channel | GPIO | Load | Notes |
|---|---|---|---|
| 1 | 25 | RESUN MPQ-03 air pump 1 (12 V, ~3.5 A) | 10 A contact rating; branch fuse per [`BOM.md`](BOM.md) #21 |
| 2 | 27 | RESUN MPQ-03 air pump 2 (N+1 standby) | Alternating duty set in firmware |
| 3 | 33 | 12 V bilge pump 1 (1100 GPH) | Water header, grid half A |
| 4 | 13 | 12 V bilge pump 2 (1100 GPH) | Water header, grid half B |

Relay module: 12 V coil, optocoupler, **low-level trigger**. JD-VCC jumper: power the relay coil from 12 V (or 5 V per module spec), keep the optocoupler side on the ESP32's 3.3 V/5 V logic rail — never back-feed 12 V into a GPIO.

## 6. Mode Selector Wiring

3-position rotary switch, 2 poles, each position **shorts the corresponding GPIO to GND** (external 10 kΩ pull-ups to 3.3 V). Decode is active-LOW:

| Position | GPIO 4 (A) | GPIO 21 (B) | Firmware decodes as |
|---|---|---|---|
| AUTO | 1 (HIGH) | 1 (HIGH) | AUTO |
| MANUAL | 0 (LOW) | 1 (HIGH) | MANUAL |
| OFF | 0 (LOW) | 0 (LOW) | OFF |

Rule: B LOW → OFF; else A LOW → MANUAL; else AUTO. OFF exists for servicing only — never while crabs are stocked.

## 7. Signal Wiring Table

| From | To | Conductor | Notes |
|---|----|---|---|
| pH board analog out | GPIO 34 | Shielded 2-core | Through 10 kΩ series + 18 kΩ shunt divider (5 V → ~3.21 V), or an ADS1115 I2C ADC for professional-grade resolution |
| EC board analog out | GPIO 35 | Shielded 2-core | Output ≤ 3.4 V — direct to ADC1 |
| DO board analog out | GPIO 36 | Shielded 2-core | Output ≤ 3.4 V — direct to ADC1 |
| DS18B20 ×2 | GPIO 16 | Shielded 3-core | Parallel on one 1-Wire bus; 4.7 kΩ pull-up to 3.3 V at the hub |
| E22 EBYTE | GPIO 18/19/23/5/14/26/17 | Short ribbon/jumpers | 3.3 V logic only — never 5 V on SPI pins |
| All sensor boards | Common GND | — | Single-point ground star at the PSU negative |

Every cable leaving the enclosure passes an IP68 gland; probe cables get drip loops so water never wicks into the box.

## 8. Power Wiring

| Segment | Spec | Notes |
|---|---|---|
| House → float | 220 V AC, 3-core 2.5 mm² earthed outdoor run | Overhead or conduit; **shore-end 30 mA RCD + 2-pole breaker**; IP67/IP68 terminations; licensed electrician |
| PSU | 12 V 30 A (360 W) switching PSU | Mounted above the waterline inside the IP65/66 enclosure, vented |
| 12 V distribution | Main fuse → per-branch blade fuses | Size fuses to conductors and loads after measuring pump inrush ([`BOM.md`](BOM.md) #21) |
| 5 V rail | LM2596S 24 V/12 V → 5 V USB module | Camera node; a second small 12 V→5 V buck is recommended to feed the ESP32 5V pin (the onboard regulator runs hot from 12 V) |
| Grounds | 12 V negative, ESP32 GND, relay GND, sensor GND | Common star point |

## 9. Pre-Energize Checklist

1. Antenna on every radio node.
2. Polarity checked with a multimeter on all three rails.
3. Relay inputs show pulled-up (relays OFF) with the ESP32 disconnected.
4. No cable under tension; drip loops formed; glands tight.
5. Branch fuses fitted and rated.
6. Bench supply first, mains last, and the electrician's sign-off before 220 V reaches the float.

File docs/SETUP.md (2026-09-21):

# Setup Guide

**Project:** Solar Automated LoRa-Integrated Mud Crab Aeration Network with Crab Grid Observation

This guide takes a builder from an empty desk to a powered, flashing, cloud-connected system. Follow it in order: software first (free), then hardware per the phased budget in [`BOM.md`](BOM.md), then first power-up on the bench.

## 1. Builder Pack Map

| File | Use it when |
|---|---|
| [`SETUP.md`](SETUP.md) (this file) | Installing tools, creating Firebase/Vercel accounts, first power-up |
| [`HARDWARE.md`](HARDWARE.md) | Component specifications and validation rationale |
| [`WIRING.md`](WIRING.md) | Assembling the float, wiring, and the verified ESP32 pin map |
| [`FIRMWARE.md`](FIRMWARE.md) | Firmware architecture, pin map, and packet protocol |
| [`TESTING.md`](TESTING.md) | Running the test plan and recording results |
| [`CALIBRATION.md`](CALIBRATION.md) | Calibrating pH, EC, DO, and temperature probes |
| [`TROUBLESHOOTING.md`](TROUBLESHOOTING.md) | Diagnosing power, boot, LoRa, sensor, and dashboard faults |
| [`APP.md`](APP.md) | Dashboard webapp features, schema, and safety interlocks |

## 2. Prerequisites

- Basic electronics skill: soldering, crimping, multimeter use.
- Tools: multimeter, soldering iron, wire strippers, crimpers, heat gun, screwdrivers, cable ties.
- **Safety gate:** all 220 V AC work (shore-end RCD, breaker, outdoor run) is a licensed-electrician job under the Philippine Electrical Code. Builders work only on the 12 V DC side.

## 3. Hardware Ordering

Order by phase so cash flow matches the project timeline (prices and links in [`BOM.md`](BOM.md)):

| Phase | Contents | Rough cost |
|---|---|---|
| 1 — Bench | 2 × ESP32 + E22/antenna, DS18B20, relay module, 1 bilge pump, selector | ₱2,906 |
| 2 — Dashboard | House bridge parts, EC sensor, refractometer, EC standards | ₱7,127–7,727 |
| 3 — Power | AC drop, RCD + breaker, 12 V 30 A PSU, LM2596S module, fuses, glands | ₱3,127–4,969 |
| 4 — Full set | DO, pH, camera, boxes, floats, frame, pipe grid, air pumps, salinity-test set | ₱34,850–46,400 |

## 4. Software Installation

1. Install **Arduino IDE 2.x** or **VS Code + PlatformIO** (PlatformIO recommended for multi-node builds).
2. Add the ESP32 board package. In Arduino IDE, File > Preferences > Additional Board Manager URLs:
   `https://raw.githubusercontent.com/espressif/arduino-esp32/gh-pages/package_esp32_index.json`
   then Boards Manager > install **esp32 by Espressif**.
3. Install the USB-serial driver for your devkit (**CH340** or **CP210x**) and confirm a COM port appears.
4. Install libraries (Library Manager or PlatformIO registry):

| Library | Used by | Purpose |
|---|---|---|
| `RadioLib` | float node, bridge | SX1262 driver for the E22-900M22S |
| `OneWire` + `DallasTemperature` | float node | DS18B20 probes |
| `DFRobot_EC`, `DFRobot_pH` | float node | EC and pH conversion with calibration |
| `Firebase Arduino Client Library for ESP8266/ESP32` (Mobizt) | house bridge | RTDB REST/realtime writes |

5. Install **Node.js LTS** and **Git** for the dashboard work.

## 5. Firebase Project

1. Create a project at console.firebase.google.com (Analytics off is fine).
2. Build > **Realtime Database** > Create database > start in locked mode.
3. Build > **Authentication** > enable **Email/Password** and create the farmer account(s).
4. Deploy database rules (Auth-only; the bridge connects server-side with its own credentials):

```json
{
  "rules": {
    ".read": "auth != null",
    ".write": "auth != null"
  }
}
```

5. Project settings > Service accounts > **Generate new private key** — keep the JSON file out of the repository; it feeds the dashboard env vars below.

## 6. Dashboard Deployment

1. Push the repo to GitHub, then import it in **Vercel** (Hobby tier) or deploy via Firebase Hosting.
2. Set the environment variables exactly as named:

| Env var | Value |
|---|---|
| `FIREBASE_DATABASE_URL` | `https://<project>-default-rtdb.firebaseio.com` |
| `FIREBASE_PROJECT_ID` | Firebase project ID |
| `FIREBASE_CLIENT_EMAIL` | Service-account email |
| `FIREBASE_PRIVATE_KEY` | Private key from the JSON (keep the `\n` escapes) |

3. Deploy and open the site; confirm the app boots with "waiting for device data" and no permission errors.

## 7. Node Configuration

Edit `firmware/<node>/config.h` before flashing (see [`FIRMWARE.md`](FIRMWARE.md) §9):

- `DEVICE_ID`: float node = 1, house bridge = 2.
- Radio settings must be **identical on every node**: 915.0 MHz, SF9, BW 125 kHz, CR 4/5, sync word 0x3444, CRC on.
- WiFi stays **off** on the float node; only the house bridge joins the network.
- The camera node is configured separately ([`FIRMWARE.md`](FIRMWARE.md) §10): AP mode, no LoRa.

## 8. First Power-Up Checklist (bench only)

1. **Attach the 915 MHz antenna before powering any radio node.** Transmitting without an antenna destroys the PA.
2. Feed the float node from a current-limited 12 V bench supply first — never from mains on the first spin.
3. Verify rails with a multimeter: 12 V ±5% at the PSU output, 5 V ±5% at the LM2596S/buck, 3.3 V ±5% at the ESP32 3V3 pin.
4. Confirm the relay module shows all channels OFF at boot (external pull-ups fitted — see [`WIRING.md`](WIRING.md) §5).
5. Flash the float node; watch the serial log for sensor init and the first LoRa uplink.
6. Flash the bridge; confirm the uplink lands in Firebase and appears on the dashboard.
7. Press the RCD test button monthly once the AC side is commissioned by the electrician.

## 9. Next Steps

- Run the bench test matrix in [`TESTING.md`](TESTING.md).
- Calibrate every probe with [`CALIBRATION.md`](CALIBRATION.md) before trusting any reading.
- Keep [`TROUBLESHOOTING.md`](TROUBLESHOOTING.md) next to the bench.

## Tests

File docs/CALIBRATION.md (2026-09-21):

# Sensor Calibration Guide

**Project:** Solar Automated LoRa-Integrated Mud Crab Aeration Network with Crab Grid Observation

Calibrate before trusting any reading, and log every calibration. Calibration constants are stored in NVS/EEPROM by the firmware ([`FIRMWARE.md`](FIRMWARE.md) §7) so a reboot never loses them.

## 1. Schedule

| Task | Frequency |
|---|---|
| pH two-point calibration | Before deployment, then every 2–4 weeks, after every probe cleaning |
| EC two-point calibration | Before deployment, monthly, after probe cleaning |
| DO single-point calibration | Before each deployment |
| DO membrane cap + electrolyte service | Monthly or on drift ([`BOM.md`](BOM.md) #25) |
| Temperature cross-check | Before deployment, monthly |
| Refractometer zero check | Weekly and before every salinity cross-check |
| RCD test button | Monthly (electrical, shore end) |

## 2. pH (E-201-C + PH-4502C)

1. Rinse the probe with distilled water and blot (never wipe) dry.
2. Calibrate with **4.01** then **6.86** buffers at pond temperature; follow the PH-4502C offset procedure and the `DFRobot_pH` two-point flow.
3. Acceptance: reading within ±0.05 pH of each buffer; slope check fails if the probe is dried out or contaminated.
4. Store the electrode in **KCl storage solution** ([`BOM.md`](BOM.md) #26) — never dry, never distilled water; the probe dies in weeks otherwise.
5. If using the 10 kΩ/18 kΩ divider, repeat the calibration after any hardware change to the divider or the ADC path; an ADS1115 path is preferred for professional-grade resolution.

## 3. EC / Salinity (DFRobot K=10)

1. Two-point calibration with **1.413 mS/cm** and **12.88 mS/cm** standards per the DFRobot K=10 procedure.
2. **12.88 mS/cm is a conductivity calibration standard, not 35 ppt seawater.** At 25 °C, 35 ppt seawater is approximately 53 mS/cm.
3. Convert calibrated EC to salinity with the manufacturer/PSS-78 method; apply temperature compensation.
4. Cross-check the converted salinity against the handheld refractometer ([`BOM.md`](BOM.md) #27) at deployment and after any rain event.

## 4. Dissolved Oxygen (SEN0237-A)

1. Service the membrane cap and electrolyte first if due; air bubbles under the membrane invalidate readings.
2. Warm up and polarize as the datasheet requires, then **single-point calibrate in water-saturated air**.
3. Provide gentle flow across the membrane during readings — stagnant water reads low.
4. Cross-check against a handheld DO meter; keep spare membrane caps and electrolyte at the bench ([`TESTING.md`](TESTING.md) SEN-04).
5. One DO probe is a single point of failure: schedule aeration as the documented fallback while the probe is serviced.

## 5. Temperature (DS18B20 ×2)

1. Cross-check both probes against a reference thermometer in the same water bath ([`TESTING.md`](TESTING.md) SEN-01).
2. A reading of **−127 °C means a wiring or pull-up fault** — see [`TROUBLESHOOTING.md`](TROUBLESHOOTING.md) §4.

## 6. Refractometer

1. Zero against distilled water at ambient temperature before use; ATC handles small drift, not bad zeros.
2. Use it as the ground truth for the EC sensor's salinity conversion — never the reverse.

## 7. Calibration Log Template

| Date | Sensor | Standards/buffers used | Offset/slope | Cross-check result | By |
|---|---|---|---|---|----|
| | | | | | |

The dashboard shows calibration due dates when `config/calibration` is filled in ([`APP.md`](APP.md) §1 and §2).

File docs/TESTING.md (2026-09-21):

# Testing and Validation Plan

**Project:** Solar Automated LoRa-Integrated Mud Crab Aeration Network with Crab Grid Observation

A gate-based test plan: no gate advances until the previous one passes. **Never test pumps or release the float in a pond with crabs stocked**, and never power a radio node without its antenna.

## 1. Test Gates

| Gate | Scope | Exit criteria |
|---|---|---|
| G1 — Bench (12 V supply) | Rails, sensors, relays, LoRa link, control logic | All PWR/SEN/ACT/LNK/CTL tests pass |
| G2 — Integrated bench | Full enclosure + pumps in buckets + bridge + dashboard | All NET tests pass |
| G3 — Field pilot (no crabs) | 7-day soak in the pond | No unexplained downtime; calibration holds |
| G4 — Stocked deployment | Thesis demo scenarios | First-aid scenarios repeatable |

## 2. Power (PWR)

| ID | Procedure | Pass criteria |
|----|---|---|
| PWR-01 | Measure 12 V, 5 V, 3.3 V rails under pump-start load | 12 V ±5%, 5 V ±5%, 3.3 V ±5%; no brownout reset |
| PWR-02 | Press the shore-end RCD test button | RCD trips; reset restores supply |
| PWR-03 | Measure each pump's running and inrush current | Within relay 10 A and branch fuse ratings; record values for fuse sizing |
| PWR-04 | Kill AC mid-run | On restoration, node boots to AUTO with aeration ON |

## 3. Sensors (SEN)

| ID | Procedure | Pass criteria |
|----|---|---|
| SEN-01 | DS18B20 pair vs reference thermometer | Within ±0.5 °C; devices found on the shared bus |
| SEN-02 | pH two-point calibration then read buffers 4.01 / 6.86 | Reads ±0.05 pH after calibration |
| SEN-03 | EC two-point with 1.413 and 12.88 mS/cm standards | Within ±2% of standard; 12.88 mS/cm is a conductivity standard, **not** 35 ppt seawater |
| SEN-04 | DO single-point (water-saturated air) then vs handheld meter | Within ±0.3 ppm of the handheld reading |
| SEN-05 | Read ADC1 pins with node WiFi off, then (on a spare node) WiFi on | Readings unchanged — proves the ADC1-only analog design |
| SEN-06 | Unplug each probe in turn | Sensor-fault bit set in the uplink within one heartbeat |

## 4. Actuators (ACT)

| ID | Procedure | Pass criteria |
|----|---|---|
| ACT-01 | Command each relay channel from MANUAL | Relay clicks; correct pump runs |
| ACT-02 | Measure delivered airflow per cage branch (jug + stopwatch or flow meter) | 0.6–0.8 L/min per cage after regulation (4.8–6.4 L/min total for 320 L) |
| ACT-03 | Run bilge pump against a valved cage outlet | Flow at the outlet; valve shuts fully |
| ACT-04 | Verify N+1 alternation across air pumps | Duty swaps without both pumps latching on |
| ACT-05 | Reset the node with pumps connected | No relay chatter at boot (pull-ups effective) |

## 5. LoRa Link (LNK)

| ID | Procedure | Pass criteria |
|----|---|---|
| LNK-01 | Bench P2P exchange both directions | Uplink and downlink verified by CRC; ACK returned |
| LNK-02 | Log RSSI/SNR at the pond edge | Stable telemetry; record the baseline for range checks |
| LNK-03 | Walk test to the house (target 1–3 km LOS) | Packets still arrive or bridge alarms are understood as the coverage limit |
| LNK-04 | Send an expired / wrong-CRC command | NAK returned; mode unchanged |

## 6. Control Logic (CTL)

| ID | Procedure | Pass criteria |
|----|---|---|
| CTL-01 | Boot the node fresh | AUTO selected; aeration relay ON |
| CTL-02 | Rotate the selector through AUTO/MANUAL/OFF | Decode matches [`WIRING.md`](WIRING.md) §6 table at every position |
| CTL-03 | Enter MANUAL and wait 5 minutes | Auto-revert to AUTO without any command |
| CTL-04 | Simulate DO below 3 ppm (feed the ADC a low value or use the test hook) | Aeration forced ON in any mode; emergency uplink sent immediately; alarm raised |
| CTL-05 | Command OFF via dashboard, then pull the bridge offline | After revert/link loss the float returns to AUTO with aeration ON |
| CTL-06 | Send a MANUAL aeration-OFF command while DO reads below 3 ppm | Command rejected (NAK) — interlock held |

## 7. Network End-to-End (NET)

| ID | Procedure | Pass criteria |
|----|---|---|
| NET-01 | Uplink → Firebase → dashboard | New values visible within one heartbeat (≤ 60 s) |
| NET-02 | Dashboard command → downlink → pump | Command lands on the next uplink cycle; ACK shown in the UI |
| NET-03 | Unplug the bridge | Heartbeat-loss alarm after 90 s; recovers cleanly |
| NET-04 | Compare uplink echo vs dashboard state | Mode and pump states always match the device's belief |
| NET-05 | Threshold edit on the dashboard | New value clamped to range; firmware applies it on the next downlink |

## 8. Field Scenarios (demonstration scenarios)

1. **Rain dilution:** add freshwater to a test bucket loop — salinity falls below `SAL_MIN`; the bilge/flush logic runs; salinity recovers in an isolated or closed-loop test volume (open-water correction is not claimed).
2. **DO depletion:** stop aeration in a test bucket until DO trends toward 3 ppm — the emergency path forces aeration and sends the emergency uplink.
3. **Link loss:** switch the bridge off — heartbeat alarm at the house; float stays in AUTO and keeps aerating.

## 9. Test Log Template

| Date | Test ID | Build/commit | Result | Notes |
|---|---|---|---|---|
| | | | pass/fail | |

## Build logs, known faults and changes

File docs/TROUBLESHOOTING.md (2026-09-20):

# Troubleshooting Guide

**Project:** Solar Automated LoRa-Integrated Mud Crab Aeration Network with Crab Grid Observation

Symptom-first fault isolation. Work top to bottom within a section; stop and cut power at the breaker for anything wet near 220 V AC.

## 1. Power and Electrical

| Symptom | Likely cause | Fix |
|---|---|-----|
| RCD trips repeatedly | Moisture in a connector or damaged insulation | Dry out, re-terminate with IP67/IP68 parts, no submerged joints; electrician to verify |
| 12 V rail sags when pumps start | Undersized conductor or weak PSU | Measure inrush ([`TESTING.md`](TESTING.md) PWR-03); upsize conductor/fuse coordination |
| Node reboots when both air pumps start | Voltage dip below brownout | Add branch fuses/decoupling; confirm PSU 30 A headroom |
| ESP32 regulator hot from 12 V VIN | Onboard LDO dissipation | Feed the 5 V pin from a small 12 V→5 V buck instead |

## 2. Boot and Flashing

| Symptom | Likely cause | Fix |
|---|---|-----|
| Boot loop or no boot | GPIO 12 pulled HIGH at reset (strap fault) | Keep GPIO 12 unconnected per the pin map ([`WIRING.md`](WIRING.md) §3) |
| "Connecting..." during flash | Board not in download mode | Hold **BOOT** while pressing RESET; check COM port and CH340/CP210x driver |
| Wrong COM port / garbled serial | Driver or baud mismatch | Reinstall driver; set monitor to 115200 |
| Board detected but upload fails | Wrong board profile | Select **ESP32 Dev Module**, 4 MB flash |

## 3. LoRa Link

| Symptom | Likely cause | Fix |
|---|---|-----|
| No packets at all | Antenna missing; freq/SF/BW/CR/sync mismatch; DIO1/BUSY miswired | Verify antenna first, then compare `config.h` on both nodes, then wiring 18/19/23/5/14/26/17 |
| CRC errors / garbage | Mismatched sync word or bandwidth | Make radio settings identical ([`FIRMWARE.md`](FIRMWARE.md) §4) |
| Intermittent reception at distance | Marginal link budget | Log RSSI/SNR (LNK-02); raise mounting height, keep LOS, stay within the NTC EIRP limit |
| Downlink never ACKed | Float busy or frame expired | Check expiry window and that commands arrive right after an uplink |

## 4. Sensors

| Symptom | Likely cause | Fix |
|---|---|-----|
| pH drifts over days | Electrode aging or dry storage | Recalibrate (2-point); store in KCl solution only ([`CALIBRATION.md`](CALIBRATION.md) §2) |
| pH reading clipped near one rail | Divider wrong or 5 V board into 3.3 V ADC | Verify the 10 kΩ/18 kΩ divider or move to ADS1115 |
| EC wildly out of range | Probe not in solution during boot; calibration lost | Recalibrate with 1.413/12.88 mS/cm standards; remember 12.88 mS/cm is not 35 ppt |
| DO stuck or reads low | Membrane fouled, bubbles under cap, no flow | Service membrane/electrolyte; provide flow across the membrane |
| DS18B20 reads −127 | Wiring fault or missing 4.7 kΩ pull-up | Check the bus and pull-up on GPIO 16 |
| Analog values change when WiFi toggles | Analog was moved to an ADC2 pin | Keep analog on 34/35/36 (ADC1) only |

## 5. Actuators

| Symptom | Likely cause | Fix |
|---|---|-----|
| Relay never clicks | GPIO not driven LOW (low-level trigger) or missing ground | Check pin map 25/27/33/13 and common ground |
| Pumps chatter at boot | Missing external pull-ups on relay inputs | Fit 10 kΩ pull-ups to 3.3 V ([`WIRING.md`](WIRING.md) §4) |
| Air pump runs, no bubbles | Air line flooded or stone clogged | Drain the line (drip loop), clean or replace the stone; re-measure branch flow (ACT-02) |
| Water header no flow | Valve closed or line air-locked | Open the per-cage valve; prime the line |
| Both air pumps latched ON | Alternation logic fault | Check the N+1 duty code; verify with ACT-04 |

## 6. Camera Node

| Symptom | Likely cause | Fix |
|---|---|-----|
| Random reboots / brownout message | Insufficient 5 V current | Feed ≥ 2 A from the LM2596S module; shorten the USB lead |
| Phone cannot join | AP not up or wrong SSID | Look for `crabcam-<id>`, reflash if absent; note the camera is WiFi-only by design |
| Stream stalls | Weak phone-to-AP link at range | Stay near the float during pond visits; this is a documented limitation |

## 7. Dashboard / Firebase

| Symptom | Likely cause | Fix |
|---|---|-----|
| Permission denied in the UI | Not signed in, or RTDB rules too tight | Sign in with the farmer account; keep the Auth-only rules from [`SETUP.md`](SETUP.md) §5 |
| Bridge not writing to RTDB | Wrong database URL or credentials | Re-check the bridge `config.h` and the service-account values |
| Vercel build fails on private key | `FIREBASE_PRIVATE_KEY` newlines lost | Re-enter the key with `\n` escapes intact |
| Dashboard shows stale data | Bridge offline or heartbeat loss | The bridge should already be alarming (90 s watchdog); restore bridge power/link |

## 8. Escalation and Safety

1. Anything wet near 220 V: **cut the breaker**, do not re-energize until the electrician clears it.
2. Keep the bench log from [`TESTING.md`](TESTING.md) §9 — fault patterns across dates are diagnostic gold.
3. If the DO probe is out of service, switch to scheduled aeration as the documented fallback until recalibration ([`CALIBRATION.md`](CALIBRATION.md) §4).

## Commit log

2026-09-11 Initial commit: project docs, components spec, and BOM
    Add README, component specifications, and Bill of Materials for the
    solar-powered LoRaWAN mud crab aeration and monitoring network.
    🤖 Generated with Codebuff
2026-09-11 Add MIT LICENSE file referenced in README
    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
2026-09-11 Add missing BOM section: protection, calibration, consumables, brine reserve
    Gap analysis found 10 items the BOM assumed but never listed (buck
    converter, LVD, fuses, cable glands, pH/EC calibration, DO membranes,
    KCl storage, refractometer, brine reserve). Update budget totals to
    ~₱67k Tier 1 / ~₱83k full and map new items to buy phases.
    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
2026-09-16 Power the prototype from the household solar AC instead of building an off-grid plant
    The site already sits on a working solar installation with a >600 Ah battery bank, so panels, MPPT and an on-site battery are no longer purchased — only a protected 220V AC drop and a 12V supply are added, and the obsolete deep-discharge LVD is replaced by AC-fail detection for the loss-of-power risk. The rest of the guide is reconciled to match: budget ranges that sum, no duplicated tables or stale battery references, corrected float/cage wording, and an accurate structure tree.
    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
2026-09-16 Switch telemetry from LoRaWAN gateway to budget point-to-point LoRa on ESP32 + RA-02
    The RAK7268 gateway and Heltec nodes (~₱14,600) are replaced by ESP32
    DevKits + EBYTE RA-02 SX1278 modules on the licence-free 433 MHz ISM band
    (~₱3,400 total), with a second node at the house bridging LoRa to the
    Firebase dashboard. Adds a WiFi/boot-safe pin map for the 38-pin DevKit
    (analog on ADC1 only, nothing on boot-strap pins), re-verifies boards
    against Makerlab PH pricing, and recomputes the full BOM, phase costs and
    ₱50,000-capped build from item level.
    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
2026-09-19 docs-audit: reconcile all scientific, electrical, and regulatory findings
    Comprehensive audit of CRAB_GRID documentation repository:
    SCIENTIFIC CORRECTIONS:
    - Buoyancy: Remove erroneous 'submerged cage wet weight' claim; document that water in slotted submerged cages is neutrally buoyant
    - Aeration: Recalculate biological target (4.8-6.4 L/min total) vs open-flow pump ratings (30-60 L/min); require flow measurement and regulation
    - Salinity: Clarify open-water brine dosing is thermodynamically impossible in slotted cages due to tidal flushing and brine sinking
    - Ammonia: Correct misconception that pH+temp alone calculates NH3; requires TAN or lab test
    - EC calibration: Fix erroneous claim t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
2026-09-20 Switch to 915 MHz LoRa primary (EBYTE E22-900M22S / SX1262)
    Change the radio band and module from 433 MHz (RA-02 / SX1278) to the
    Philippine NTC licence-free 915 MHz SRD band (EBYTE E22-900M22S / SX1262).
    RADIO / MODULE:
    - E22-900M22S uses Semtech SX1262 (not SX1276/SX1278), +22 dBm
    - SX1262 pin map differs: DIO1 (IRQ) on GPIO 26 instead of DIO0, plus a
    required BUSY line on GPIO 17 (no BUSY on SX127x)
    - Library changes from sandeepmistry/LoRa (SX127x-only) to RadioLib SX126x
    - 3.3V logic only; never 5V on the SPI pins
    REGULATORY:
    - Flip from 'verify 433 MHz' to '915 MHz is the PH licence-free SRD band'
    for low-duty telemetry; confirm max EIRP + type-approval before deployment
    BUDGET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
2026-09-20 docs-final: fix stale AI-isms and audit-report footers
    - BOM: remove 'note that' AI-ism in DO probe consumables row
    - AUDIT_REPORT: remove 'by Hermes Agent comprehensive audit' footer; stale
    report state is now noted as addressed by prior commits
    - Concept-Questions.md already clean; no stale 433/off-grid remnants found
    This brings the documentation set to a final, clean state aligned with the
    915 MHz LoRa primary (E22-900M22S/SX1262) architecture.
2026-09-20 BOM: specify RESUN MPQ-03 (MPQ-903) air pump; fix aeration/power budget
    Replace the generic 30-60 L/min air pump pick with the verified model the
    user selected for the build: RESUN MPQ-03 (MPQ-903) 12V electromagnetic air
    pump — 35W, 68 L/min open-flow, 0.068 MPa, ~3.5A, 6 outlets.
    Spec + sizing changes swept across README, Components, BOM, Concepts:
    - Air pump rows now name MPQ-03; clarify 2 units = N+1 redundancy (alternating
    duty), not per-cage capacity, since 68 L/min is huge headroom vs the
    4.8-6.4 L/min delivered biological target for 320 L
    - Compatibility #8 aeration: note MPQ-03 68 L/min open-flow
    - Compatibility #7 load vs relay/supply: air pump ~3.5A (was <2A); peak burst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
2026-09-20 chore: merge Components+BOM into HARDWARE.md (gitignored), remove AUDIT_REPORT.md
    - Merged Components.md and docs/BOM.md into single HARDWARE.md
    - Added HARDWARE.md to .gitignore (local-only file)
    - Removed AUDIT_REPORT.md from repo
2026-09-20 docs(BOM): add grand total summary table
    - Added GRAND TOTAL SUMMARY section with 4 build configurations
    - Added Quick Reference table showing what's included per tier
    - Updated both BOM.md and local HARDWARE.md for consistency
2026-09-20 docs(BOM): upgrade floats to 4× round 50×90cm solid foam, reduce floaters from 8-12 to 4 units
    - Item #16: Replace generic foam floats with 4× Round plastic shell + solid foam 50×90cm (₱2,643/pc, 4.9★)
    - Each float supports ~163 kg usable buoyancy (2:1 safety factor), can hold 2 crab cages
    - Updated structure cost: ₱18,264–21,264 (was ₱11,200–16,700)
    - New totals: Tier 1 ₱39,787–48,879 | Full Set ₱53,182–63,473
    - 50K Cap (cuts 1–2): ₱39,934–48,526 (fits under ₱50K!)
    - Removed redundant text from item #16 notes
    - Updated README budget sections
2026-09-20 docs: add builder guide set, move all guides into docs/, strip emojis
    - Add 11 new guides: SETUP, WIRING, FIRMWARE, TESTING, CALIBRATION,
    TROUBLESHOOTING, APP, plus thesis diagrams FLOWCHART, SYSTEM-ARCHITECTURE,
    BLOCK-DIAGRAM and STACKS (Mermaid, thesis format)
    - Move every guide MD into docs/ so only README.md stays at root;
    rewrite all cross-links (README -> docs/, same-folder within docs/,
    parent refs in BOM, references/ -> ../docs/)
    - Remove all emojis and icons across the documentation, convert star
    ratings to text; fix MANUAL revert conflict to the 5-minute standard
    and align the BOM downlink payload with FIRMWARE.md section 5.2
    Co-Authored-By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
2026-09-21 Add ammonia risk estimation section, remove thesis references
    - Add Ammonia Risk Estimation guide to BOM.md and Components.md
    - Emerson/Khoo formula for pKa and unionized NH3 fraction
    - Practical implementation table (with/without TAN measurements)
    - Quick reference table for CRAB_GRID conditions (pH 7.5-8.5, Temp 27-30C)
    - Dashboard warning logic (alert at pH>8.2 + temp>28C)
    - Reference: Millero et al. (2006) Chemical Reviews
    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
2026-09-21 Remove sources and validation notes from BOM.md header
2026-09-21 Remove historical design-change note from BOM §1
2026-09-21 Remove ammonia section and design-change notes from BOM.md
2026-09-21 Remove design-change note from BOM §8
2026-09-21 Remove design-change notes and timestamps from BOM and Components
2026-09-21 Remove large image from tracking, add wiring/*.png to gitignore
2026-09-21 Add wiring project files and CirKit Designer reference
2026-09-21 Update ESP32-CAM to ESP32-CAM-MB across all docs
2026-09-21 Add wiring circuit diagram PNG
2026-09-21 Update CirKit wiring diagram files
2026-09-29 Included smart crab aeration 3d model files
    [SmartCrabAeration.f3d]
